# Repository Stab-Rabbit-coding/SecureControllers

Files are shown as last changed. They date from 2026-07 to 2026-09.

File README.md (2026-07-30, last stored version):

# SecureControllers
unmanned system controllers with security baked in. 

These started as the avionics suite for the Serenity UAV, but aren't limited to that.

1. EMI-Hardened Beagle Capes

    * PocketBeagle2-I Secure Flight Controller
    * PocketBeagle2-I Secure Communications
    * PocketBeagle2-I Sub-Gigahertz Trustworthy Transceiver

2. Trustworthy Sensor R-PI HATs

2. Trustworthy Gateway devices

    * Stackable CAN+RS-485 peripherals Gateway for GPIO/SPI/TTL/ADC/DAC/UART with a TPM.

3. Trustworthy Final Control Elements

    * 50A ESC
    * digital servo
    * Camera/Laser pod
    * Power Distribution Board

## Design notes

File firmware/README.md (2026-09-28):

# Serenity UAV — Firmware

**Author:** Steve Griffing, PE(CSE), CISSP-ISSEP, CPP
**License:** CC BY 4.0 — creativecommons.org/licenses/by/4.0
**Status:** Phase 6 — Minimum Viable Firmware for First Flight

---

## Overview

This directory contains the userspace firmware daemons that run on the eight
PocketBeagle 2 Industrial (AM6254) single-board computers in the Serenity UAV.

The AM6254 runs **BeagleBone Debian Trixie** from onboard 64 GB eMMC; these daemons
are standard Linux processes that use POSIX APIs, i2c-dev, libgpiod 2.x, and pthreads.

## Node Groups

| Group | Count | Cape | Responsibilities |
| --- | --- | --- | --- |
| FC nodes | 4 | Cape-A | Flight control, navigation, obstacle avoidance, ESC/actuator drive |
| CN nodes | 4 | Cape-B | Radio links, system logging, payload/cargo management |

## Cape Variant Placement

The eight nodes use a **v2 · v2 · v2 · v2** (nose → tail) cape variant layout — Rev R all-EMI-hardened:

| Bay | Room name | Pair | FC cape | CN cape | Rationale |
|-----|---|---|---|---|---|
| A (nose) | Shepherd's room | FC1 / CN1 | Wash | TACCO | Bus start termination; 5 kV isolated CAN FD / RS-485 / Ethernet at forward bus endpoint |
| B | Inara's shuttle | FC2 / CN2 | Wash | TACCO | Rev R: uniform EMI hardening across all bays |
| D | River's room | FC3 / CN3 | Wash | TACCO | Rev R: uniform EMI hardening across all bays |
| E (tail) | Simon's medbay | FC4 / CN4 | Wash | TACCO | Bus end termination; 5 kV isolation closest to nacelle motor wiring / rear EDF |

Rev R places 5 kV galvanic isolation at every node. Cape-A-1 / Cape-B-1 are archived (Rev Q, 2026-06-05).

## Directory Layout

```text

firmware/
├── common/
│   └── include/         # Shared headers used by both FC and CN daemons
│       ├── kiss_types.h # KISS protocol constants (RFC 1055 / Chepponis & Karn 1987)
│       └── ax25_types.h # AX.25 v2.2 frame type definitions
├── cn/                  # CN node daemon (runs on all 4 Cape-B / AM6254 nodes)
│   ├── CMakeLists.txt
│   └── src/
│       ├── main.c       # Daemon entry point, argument parsing, signal handling
│       ├── si5351.h     # Si5351A DDS I²C driver API
│       ├── si5351.c     # Si5351A frequency programming (49 MHz Part 15 §15.235 channels)
│       ├── xcvr_kiss.h  # XCVR-49MHZ-1 KISS/AX.25 driver API
│       └── xcvr_kiss.c  # KISS framing, PTT sequencing, UART I/O
├── fc/                  # FC node daemon (stub — Phase 7)
│   ├── CMakeLists.txt
│   └── src/
│       └── main.c       # FC node entry point stub
└── CMakeLists.txt       # Top-level build

```

## Build

### Target Platform

| Item | Value |
| --- | --- |
| Board | PocketBeagle 2 Industrial (DigiKey 2820-100003007-ND) |
| SoC | TI AM6254 (quad Cortex-A53 @ 1.4 GHz, dual PRU-ICSS) |
| OS | BeagleBone Debian Trixie (libgpiod 2.2.1, Linux ≥ 6.1) |
| Storage | 64 GB eMMC (no OS microSD) |

### Prerequisites (cross-compilation host, Ubuntu 24.04+)

```bash

# Cross-compiler and CMake

sudo apt install cmake gcc-aarch64-linux-gnu libc6-dev-arm64-cross

# libgpiod 2.x headers and static lib for aarch64

# Debian Trixie sysroot required — or use multiarch on a Trixie host:

#   sudo dpkg --add-architecture arm64

#   sudo apt install libgpiod-dev:arm64

```

> **NOTE:** Builds shall use **libgpiod 2.x** (Debian Trixie ships 2.2.1).
> The libgpiod 1.x API (Ubuntu 24.04) is **incompatible** with this code.
> Build directly on a PocketBeagle 2 or in a Trixie arm64 container if
> a full cross-compilation sysroot is not available.

### Build on the PocketBeagle 2 itself (simplest for Phase 6)

```bash

# On the PocketBeagle 2 running Debian Trixie:

sudo apt install cmake build-essential libgpiod-dev

git clone <repo> && cd Serenity-UAV/serenity/firmware
mkdir build && cd build
cmake ..
cmake --build .
sudo cmake --install .

```

### Cross-compile for AM6254 (aarch64) — advanced

```bash

mkdir build && cd build
cmake .. -DCMAKE_TOOLCHAIN_FILE=../cmake/aarch64-linux-gnu.cmake
cmake --build .

```

## Deployment

```bash

# Install via cmake on the target, or copy manually:

scp build/cn/serenity-cn debian@pocketbeagle2-cn1:/usr/local/bin/
scp build/fc/serenity-fc debian@pocketbeagle2-fc1:/usr/local/bin/

```

Systemd unit files are in `cn/serenity-cn.service` and `fc/serenity-fc.service` (Phase 7).

## Security

All inter-node messages are digitally signed using the node's TPM 2.0 (SLB9670).
The signing key is bound to the TPM's PCR state at boot (measured boot).
The AX.25 payload carries a SHA-256 HMAC before KISS framing; the CN node
verifies the HMAC on received frames before forwarding to the AX.25 stack.
Key management uses the Linux TPM2 PKCS#11 provider (`pkcs11-provider`).

## References

- AX.25 Link Access Protocol v2.2, ARRL, 1998
- KISS TNC Protocol: Chepponis & Karn, ARRL 6th Computer Networking Conference, 1987
- Si5351A/B/C-B Datasheet, Skyworks (formerly Silicon Labs), Rev 1.4
- 47 CFR Part 15 §15.235 — Operation within the band 49.82–49.90 MHz
- libgpiod API documentation — kernel.org
- Linux i2c-dev interface — kernel.org/doc/Documentation/i2c/dev-interface.rst

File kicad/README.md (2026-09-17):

# Serenity Avionics — KiCad Cape Status & Build Notes

This directory holds the KiCad projects for the four cape/board types:

| Project | Name | Role |
| --- | --- | --- |
| `Wash.kicad_*` | **Wash** | Flight-control & sensor cape (FC) |
| `TACCO.kicad_*` | **TACCO** | Comms / logging / payload cape (CN) |
| `FlightEngineer.kicad_*` | **FlightEngineer** | Power-distribution board (PDB) |
| `Emma.kicad_*` | **Emma** | 49 MHz (Part 15 §15.235) transceiver |
| `Observer.kicad_*` | **Observer** | Nose/Cargo vision, ToF, & laser board (standalone) |

Per-board net/pin documentation lives in the matching `*.md` files
(`Wash.md`, `TACCO.md`, `FlightEngineer.md`, `XCVR-49MHZ-2.md`). KiCad files keep
KiCad board coordinates (documented exception to the hull-frame standard,
see root `CLAUDE.md`).

---

## DRC / routing work — what was done and what was not (2026-06-12)

A pass was made to wire in a second Ethernet channel and to clear the
Design-Rule-Check (DRC) and ratsnest issues introduced by a manual
component rearrangement. This section records exactly what landed and
what is still open, so the thread can be picked up cleanly.

### ✅ Done

- **Second Ethernet (ETH2) wired on Wash.** The newly placed `ETH2`
  (JST-GH-4P), `ETH2-PHY` (ADIN1300BCPZ), and `T-ETH2` (749010012A
  magnetics) footprints were present but unconnected. Their nets now
  mirror the ETH1 topology exactly:

  ```text
  ETH2 ──ETH2_LINE_{TX,RX}{P,N}──► T-ETH2 ──ETH2_{TX,RX}{P,N}──► ETH2-PHY
  ```

  The host side reuses the nets already broken out on the **PB2-P2**
  header: the `RMII1_*` bus, shared `MDIO`/`MDC`, `PHY2_INTRN`/
  `PHY2_RSTN`, and the `VCC2_ETH` / `GND` / `GND2_ETH` power and
  isolation domains. 44 pads assigned (ETH2-PHY 32, T-ETH2 8, ETH2 4);
  diff-pair chains verified end-to-end. *(Delivered in PR #59.)*

- **Split the two Wash PHYs onto independent MDIO buses (2026-06-12).** Instead
  of an address strap on a shared bus, PHY1 now uses `MDIO0`/`MDC0` (the CPSW
  MDIO controller, PB2-P2 pins 17/18) and PHY2 uses `MDIO1`/`MDC1` (PB2-P2 pins
  1/2, the two spare servo channels SERVO6/7). Each PB2-I NIC manages its own
  PHY — no shared-address conflict. Both the PCB nets and the schematic global
  labels were updated. *Firmware note:* PHY2's bus is a second (bit-banged
  `mdio-gpio`) MDIO; confirm the two repurposed balls are GPIO-capable in the
  PB2-I pinmux.

- **Wired the floating field connectors to their signals (2026-06-12).** Every
  JST field connector was placed but had no nets. Using each footprint's
  Description pinout: SERVO-PWM pads 1–6 → `SERVO0–5` (servo PWM); ESC-TLM →
  `UART_ESC_TX`/`RX`; GPIO-A…F → `GND`/`+3V3` (+ labelled `GPIO_EXP_*` signal);
  CAN-FD → `CAN_H`/`CAN_L`; RS-485 → `RS485_A`/`B`; PWR-IN → `+5V`/`GND`. The
  new connector shorts that DRC now reports are all against `TMESH_*` (the
  pre-existing tamper-mesh overlap, resolved by the mesh rework below) — not the
  connector wiring itself.

- **Confirmed the design is PCB-driven.** Each cape's schematic
  (`*.kicad_sch`) defines only the PocketBeagle-2 header pin-mux (the
  PB2-P1/P2 connectors with the RMII0/RMII1/MDIO net labels); every other
  component lives as a PCB footprint with nets assigned directly on the
  board. "Update PCB from Schematic" therefore does **not** repopulate
  the component nets — net edits are made on the `.kicad_pcb`.

- **Verified the boards load** in `pcbnew` (Wash 43, TACCO 42, Emma 69,
  FlightEngineer 67 footprints) and characterised the violation landscape (below).

### ❌ Not done — open follow-up

1. **Tamper mesh (`TMESH_P`/`TMESH_N`).** Drawn today as a raw
   cross-hatch grid on F.Cu/B.Cu that **shorts across SMD pads and across
   the isolated `GND2_*` domains** — this is the single largest source of
   DRC errors (≈335 of Wash's 465; similar on TACCO). The agreed design is
   a **per-domain anti-tamper mesh**: a separate monitored mesh net per
   isolation region (secure/`GND` area plus one per `GND2_CAN` / `GND2_ETH`
   / `GND2_RS485` field side), with the 0.5 mm `ISOLATION` creepage moat
   kept clear between them. Wash and TACCO tie their mesh to the local TPM;
   **FlightEngineer and Emma have no local TPM**, so their tamper signal must be
   carried over the inter-board link (Emma → TACCO, FlightEngineer → Wash).

2. **Routing / ratsnest.** The manual rearrangement left signal nets
   unrouted (~60 multi-pin signal nets per cape; the 7 power/ground nets
   are intended as planes). This was **not** completed — see the toolchain
   findings below for why headless autorouting did not produce a
   trustworthy result. The impedance-controlled Ethernet pairs should be
   routed interactively (length-matched / controlled-impedance) regardless.

3. **Remaining DRC.** After the mesh and routing are fixed, the residual
   cosmetic/footprint items still need clearing (counts measured
   2026-06-12, error+warning):

   | Board | violations | unconnected | dominant types |
   | --- | --- | --- | --- |
   | Wash | 465 | 121 | mesh shorts, solder-mask bridges, clearance |
   | TACCO | 554 | 146 | mesh shorts, solder-mask bridges, clearance |
   | Emma | 421 | 160 | silk-over-copper, text-height, mask bridges |
   | FlightEngineer | 221 | 181 | courtyard overlap, lib-footprint mismatch, silk |

4. **MDIO addressing.** Both Wash PHYs (ETH1-PHY, ETH2-PHY) share the
   `MDIO`/`MDC` management bus but there are **no address-strap resistors
   on the board**, so both default to the same MDIO address. A strap
   (or a decision to manage each PHY only over its own RMII channel) is
   required before the second PHY is manageable. Not invented here because
   no strap-resistor footprints are placed.

---

## Toolchain findings (headless KiCad 9 + freerouting)

These are recorded so the next person does not re-derive them:

- **KiCad 9.0.2 `pcbnew.ExportSpecctraDSN()` is non-functional in
  standalone Python** — it returns `False` with no GUI/kiway context
  (`pcbnew.GetBoard()` is `None`). Loading a project, building
  connectivity, initialising a `wx.App`, and running under Xvfb all make
  no difference; it is a binding limitation, not a display issue.

- A custom headless **Specctra DSN exporter + SES importer** (driven
  entirely through the working board API) was written to bridge this. The
  round-trip is mechanically correct (valid DSN out, freerouting routes
  it, SES tracks/vias re-imported at the right coordinates).

- **freerouting 2.1.0 headless is unreliable for a complete route on this
  toolchain**: it must be run **without** a display (with Xvfb it opens
  the GUI and hangs); it never self-exits (must be killed after the SES is
  written); its multi-threaded optimiser is broken (use `-mt 1`); and the
  SES it emits captured only a handful of nets rather than the full
  ~60-net set. It was therefore **not** used to route the boards.

- **Recommended workflow:** finish routing in the **KiCad GUI** (where
  Specctra DSN export and the interactive/auto routers are reliable), with
  the Ethernet pairs routed by hand. The deterministic, non-routing work
  (per-domain tamper-mesh zones, cosmetic/footprint DRC, the Emma/FlightEngineer
  link tamper signalling) can still be scripted headless via the board API.

---

*Author: Steve Griffing, PE(CSE), CISSP-ISSEP, CPP · License: CC BY 4.0*

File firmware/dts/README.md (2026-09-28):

# Serenity UAV — Device Tree Overlays

**Author:** Steve Griffing, PE(CSE), CISSP-ISSEP, CPP
**License:** CC BY 4.0 — creativecommons.org/licenses/by/4.0
**Status:** Phase 6 — Minimum Viable Firmware for First Flight

---

## Overview

This directory contains the AM62X device tree overlays that configure the
PocketBeagle 2 Industrial (AM6254) peripherals for the Serenity UAV Cape-A
and Cape-B expansion boards.

| Overlay | Cape | Node | Peripherals |
| --- | --- | --- | --- |
| `cape-a/k3-am6254-pocketbeagle2-serenity-cape-a.dtbo` | Cape-A | FC nodes (4×) | IMU, barometer, TPM, ToF, GNSS, RS-485, CAN FD, Ethernet, EHRPWM, MIL-STD-1553 |
| `cape-b/k3-am6254-pocketbeagle2-serenity-cape-b.dtbo` | Cape-B | CN nodes (4×) | TPM, LoRa, NOR flash, logging SD, SiK radio, RS-485, 49 MHz (Part 15 §15.235), CAN FD, Ethernet, WiFi, cargo servo, MIL-STD-1553 |

## Prerequisites

```bash

# On the PocketBeagle 2 (Debian Trixie) or cross-compilation host:

sudo apt install device-tree-compiler    # provides dtc 1.7.x

```

`dtc` version 1.7 or later shall be used, for the `-@` flag (generates
`__symbols__` section enabling runtime overlay application).

## Build

```bash

cd serenity/firmware/dts
make

```

This produces `cape-a/*.dtbo` and `cape-b/*.dtbo`.

## Install

```bash

# Copy compiled overlays to the PocketBeagle 2 boot partition.

# Must be run as root on the target board.

sudo make install

```

Then edit `/boot/firmware/extlinux/extlinux.conf` and add the appropriate
`fdtoverlays` line under your `LABEL` stanza:

```text

# FC nodes (Cape-A):

fdtoverlays /overlays/k3-am6254-pocketbeagle2-serenity-cape-a.dtbo

# CN nodes (Cape-B):

fdtoverlays /overlays/k3-am6254-pocketbeagle2-serenity-cape-b.dtbo

```

Each node loads only one overlay (the one matching its installed cape).

## Pad Offset Verification

All `AM62X_IOPAD` offsets tagged `[ESTIMATE]` in the DTS source files
**shall be verified** before production use by cross-referencing:

1. **TI AM6254 TRM, SPRUJ40**, Table 7-1 "MAIN Domain Pad Control Registers"

- Step 2: **PocketBeagle 2 Industrial schematic** (BeagleBoard.org hardware repo),

   which maps AM6254 ball numbers to P1/P2 expansion header pins.

Offsets tagged `[CONFIRMED]` are sourced from `k3-am625-sk.dtsi` in the
Linux 6.x kernel tree and have been validated against production hardware.

GPIO line numbers are logical (relative to `main_gpio0`) and shall also
be verified against the PocketBeagle 2 expansion header pin map.

## Cape-A Peripheral Details

| Peripheral | Interface | Linux Driver | Notes |
| --- | --- | --- | --- |
| ICM-42688-P IMU | SPI0 CS0 | `invensense,icm42688p` | SPI mode 3, 24 MHz |
| BMP388 barometer | SPI0 CS1 | `bosch,bmp388` | SPI mode 0, 10 MHz |
| SLB9670 TPM 2.0 | SPI0 CS2 | `infineon,slb9670` | 33 MHz, IRQ + RST GPIO |
| TCA9548A I²C mux | I2C2 0x70 | `nxp,pca9548` | 8-ch, 400 kHz |
| VL53L5CX ToF ×2 | I2C2 mux ch0/1 | `st,vl53l5cx` | 0x29, share addr |
| MS4525DO airspeed | I2C2 mux ch2 | `ms4525do` | FC1 only |
| Debug console | UART0 | n/a | 115200 8N1 |
| ESC telemetry | UART1 | n/a | BLHeli32 / Hobbywing |
| u-blox M10Q GNSS | UART3 | gpsd | 38400 baud default |
| RS-485 MAX3485E | UART4 | n/a | DE/RE# GPIO direction |
| CAN FD ATA6561 | MCAN0 | `m_can` | 1/8 Mbps |
| Ethernet DP83825I ×2 | CPSW3G | `dp83825i` | 100BASE-TX RSTP ring |
| EHRPWM 0-2 | — | `pwm` | 6ch servo/ESC PWM |
| MIL-STD-1553B | PRU-ICSS0 PRU0 | n/a | Manchester II 1 Mbps |
| Extra PWM ch 6-7 | PRU-ICSS0 PRU1 | n/a | 1 µs resolution |

## Cape-B Peripheral Details

| Peripheral | Interface | Linux Driver | Notes |
| --- | --- | --- | --- |
| SLB9670 TPM 2.0 | SPI1 CS0 | `infineon,slb9670` | HMAC keys for radio frames |
| RFM95W LoRa 915 | SPI1 CS1 | `semtech,sx1276` | 47 CFR Part 15 Subpart C |
| W25Q128JV NOR flash | SPI1 CS2 | `jedec,spi-nor` | 16 MiB, 3 partitions |
| Logging microSD | SPI1 CS3 | `mmc-spi-slot` | ext4, noexec, CPLD WP |
| RFD900x SiK 915 MHz | UART2 | n/a | MAVLink, HW CTS/RTS |
| RS-485 MAX3485E | UART4 | n/a | DE/RE# GPIO direction |
| XCVR-49MHZ-1 (49 MHz Part 15) | UART5 | n/a | AX.25, 57600 8N1, PTT_N GPIO |
| CAN FD ATA6561 | MCAN0 | `m_can` | 1/8 Mbps |
| Ethernet DP83825I ×2 | CPSW3G | `dp83825i` | 100BASE-TX RSTP ring |
| WL1837MOD WiFi | MMC1 / SDIO | `ti,wl1837` | 5 GHz 802.11ac, 4-bit |
| EHRPWM0 | — | `pwm` | 2ch cargo servo/gimbal |
| MIL-STD-1553B | PRU-ICSS0 PRU0 | n/a | RT mode only on CN nodes |
| Cargo PWM + TDDS | PRU-ICSS0 PRU1 | n/a | 2ch servo + Si5351 sync |

## PRU Firmware

PRU firmware binaries shall be installed to `/lib/firmware/serenity/` on
the target before loading the overlays:

```bash

sudo mkdir -p /lib/firmware/serenity/
sudo cp pru0-mil1553.out   /lib/firmware/serenity/
sudo cp pru1-servo-pwm.out /lib/firmware/serenity/    # Cape-A PRU1
sudo cp pru1-cargo-servo.out /lib/firmware/serenity/  # Cape-B PRU1

```

PRU firmware source is in `serenity/firmware/pru/` (Phase 7).

## References

- TI AM6254 Technical Reference Manual, SPRUJ40
- TI AM62x SK EVM device tree, `k3-am625-sk.dtsi`, Linux 6.x kernel
- PocketBeagle 2 Industrial schematic — BeagleBoard.org hardware repository
- BeagleBone Debian Trixie `extlinux.conf` overlay documentation
- MIL-STD-1553B, DoD Interface Standard, 21 Sep 1978
- 47 CFR Part 15 §15.235 (49 MHz channel plan; not Part 95 RCRS, which does not cover this band)
- 47 CFR Part 15 Subpart C (unlicensed 915 MHz LoRa)

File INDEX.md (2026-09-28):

# Workspace Resource Index

`SecureControllers` is the canonical library for reusable hardware design
assets across the Browncoats workspace (`designs/`) — **copy-with-index**,
not a git submodule or symlink. Canonical, verified copies of shared
datasheets, KiCad symbols/footprints, and mechanical shapes live in this
repo's `datasheets/`, `kicad/`, and `shared.3dshapes/` directories, each with
a recorded SHA-256 hash. Consuming repos keep their own local copies; this
index is how you check whether yours matches the canonical one, and where to
find a verified asset before adding a new copy.

This repo also carries a full local library of **agent skills** (128, under
`.claude/skills/`) usable by any Claude Code session — local or cloud/web —
running against this repo or branch. That library has its own token-optimized
index: [`.claude/skills/INDEX.md`](.claude/skills/INDEX.md). Same lookup
pattern as this file, different asset type — use that one for "which skill do
I invoke for this task," use this one for "which datasheet/symbol/footprint/
shape/script already exists."

Full plan and rationale:
[`docs/plans/2026-09-08-001-feat-workspace-resource-library-plan.md`](docs/plans/2026-09-08-001-feat-workspace-resource-library-plan.md).
GitHub issue tracking all four phases:
[`SecureControllers#1`](https://github.com/Stab-Rabbit-coding/SecureControllers/issues/1).

## How to look something up (minimum token cost)

Read **one** manifest file below for your asset type — never grep the PDFs,
`.kicad_sym`/`.kicad_mod` files, or shape files themselves, and never load
more than one manifest for a single lookup.

| Looking for... | Read this file | Key field to match on |
| --- | --- | --- |
| A datasheet by part number | `index/datasheets.json` | `mpn_guess` (Tier B-confirmed once `verified: true`) |
| A KiCad symbol | `index/kicad-symbols.json` | `symbol_or_footprint_name` |
| A KiCad footprint | `index/kicad-footprints.json` | `symbol_or_footprint_name` |
| A mechanical shape (STEP/WRL/STL) | `index/shapes.json` | `basename` |
| A shared script/tool | `index/scripts.json` | `path` |
| A workspace-wide knowledge resource (e.g. `engineering-pe-skills`) | `index/knowledge.json` | `path`, `description` |
| An agent skill available in *this* repo | `.claude/skills/INDEX.md` (or `index/skills.json`) | skill directory name, `description` |
| Whether a repo has assets yet | `index/placeholders.json` | `repo` |

There is currently no single-file "everything from repo X" lookup — that
would require reading each type manifest and filtering by `repo`. See the
Open Questions in the plan (per-repo lookup surface) before relying on one;
none exists yet.

Every entry carries `verification_tier` (`unverified` until Phase 2 runs,
then `"A"` = full pin/pad-verified, `"B"` = provenance/hash-verified, `"C"` =
placeholder-only) and `verified: true/false`. An entry with
`possible_duplicate: true` or `renamed_duplicate: true` has a same- or
differently-named twin in another repo — check `canonical_path` (once Phase 3
runs) for which copy is authoritative.

## Current scope (as of the last scan)

| Repo | Datasheets | KiCad symbols | KiCad footprints | Shapes | Scripts |
| --- | ---: | ---: | ---: | -----: | ---: |
| Serenity-UAV | 50 | 9 | 17 | 367 | 46 |
| SecureControllers | 48 | 8 | 15 | 37 | 3 |
| Open-Secure-ESC | 58 | 20 | 9 | 1 | 0 |
| open-servo-core-secure | 11 | 1 | 40 | 37 | 0 |
| LibreServo_v4 | 26 | 2 | 22 | 3 | 0 |
| Tactical-WX-RX | 3 | 0 | 0 | 0 | 0 |

"Scripts" counts only top-level `tools/` directories (per the provisional
classification rule below) — nested per-board generator/fixup scripts (e.g.
`Open-Secure-ESC`'s many `kicad/<board>/tools/*.py` one-offs) are
intentionally excluded, not missed.

`engineering-pe-skills` is indexed separately as a **knowledge asset** (4
skill entries in `index/knowledge.json`) — it has no MPN/hash-drift concerns
in the hardware sense, but is still a citable reusable resource.

**Placeholder-hook repos** (no hardware assets yet — `index/placeholders.json`):
Bento-boat, TidySweep, obd2-recorder, dasGoat-USV. Consult this index when
starting hardware work in any of them.

**Confirmed cross-repo duplication:** 87 of 175 cataloged datasheets and 74 of
445 shape entries (`possible_duplicate: true` in `index/datasheets.json` /
`index/shapes.json`) already have a same-named copy in another repo — this is
exactly the drift risk this index exists to catch. 4 renamed-but-content-
identical datasheet duplicates were also found (`renamed_duplicate: true`).

## Verification tiers (Phase 2 / U4, not yet run)

- **Tier A** — full pin/pad-level check against the source datasheet. Applied
  to flight-critical parts and anything already flagged as suspect (e.g. the
  7 known-bad Wash footprints tracked in `TODO.md`).
- **Tier B** — provenance + cross-repo hash-consistency check. Everything
  else.
- **Tier C** — placeholder only, no file to verify (the four empty repos).

See the plan's Open Questions for two items that block a clean Tier-A pass:
worklist completeness for un-audited flight-critical parts, and the
provisional "scripts live under `tools/`" classification rule used by
`tools/inventory_scan.py`.

## Regenerating the index

```bash
/usr/bin/python3 tools/inventory_scan.py    # rescan all repos -> index/_raw/*.json
/usr/bin/python3 tools/build_manifests.py   # rebuild index/*.json from the raw scan
```

Both scripts are stdlib-only (no `kiutils`/`manifold3d` dependency) and shall
be run with `/usr/bin/python3`, not a repo's local `.venv`, which shadows
system packages without providing everything the workspace tooling needs.

## Cross-links from consuming repos

Each consuming repo's own `AGENTS.md`/`CLAUDE.md` carries a one-line pointer
back to this file (Phase 4 / U6) — check there first if you arrived at a
board's design docs and are wondering whether an asset already exists
elsewhere in the workspace.

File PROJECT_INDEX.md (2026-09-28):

# Project Index — SecureControllers

Directory structure and active files, per the repository-root governance
convention in the user's global `CLAUDE.md`. For high-volume, single-format
directories (datasheets, KiCad symbols/footprints, shared 3D shapes), this
file gives the directory-level shape; the authoritative per-file listing
(with hash, MPN guess, verification tier, and cross-repo duplicate flags) is
[`INDEX.md`](INDEX.md) and the machine-readable manifests under `index/`.
Duplicating hundreds of filenames here as well would drift out of sync with
the generated manifests on every rescan — regenerate `index/*.json` via
`tools/inventory_scan.py` / `tools/build_manifests.py`, not this file, and
treat those as the source of truth for asset inventories.

## Root

| Path | Purpose |
| --- | --- |
| `.claude/` | Claude Code project config; `.claude/skills/` is the local agent-skills library (128 skills) — see below |
| `CLAUDE.md` | Avionics design project instructions (Serenity-UAV subsystem scope; this repo also serves as the workspace library — see Open Questions in the plan below) |
| `.gitignore` | Excludes `__pycache__/`, `*.pyc` |
| `INDEX.md` | Workspace resource library entry point — read this first for asset lookups |
| `LICENSE.md` | Repository license |
| `not-a-real-datasheet.txt` | Test fixture (deliberately not a real datasheet; excluded from the scanner's matched extensions) |
| `PROJECT_INDEX.md` | This file |
| `SecureControllers.code-workspace` | VS Code workspace file |
| `TODO.md` | Work Breakdown Structure. Currently scoped as "Serenity UAV — Avionics WBS"; identity vs. this repo's new workspace-library role is an open question in the plan (see `docs/plans/`) |

## `.claude/skills/`

128 agent skills (security/SOC, GRC compliance, PE-aligned engineering,
PCB/KiCad, compound-engineering, dev-workflow) mirrored into this repo from
the user's `~/.claude/skills/` and plugin installs, so they're available to
any Claude Code session — local or cloud/web — running against this repo or
branch, not just this machine. Human/agent-searchable index, grouped by
category, one-line description per skill:
[`.claude/skills/INDEX.md`](.claude/skills/INDEX.md). Machine-readable form:
`index/skills.json`. Regenerate after adding/removing/editing a skill:
`python3 tools/build_skills_index.py`.

Excluded from this mirror: `pr-review-toolkit`, `security-guidance`, and
`github` plugins — they ship as agents/hooks/commands, not `SKILL.md`
folders, so there was nothing skill-shaped to copy.

## `datasheets/`

48 manufacturer/standards PDFs (ISOW1044, SLB9670, ADIN1300, ADM2795E,
BMP388, SAM-M10Q, NIST SP 800-series, etc.). Full per-file listing with
MPN guesses: `index/datasheets.json`.

## `docs/`

| Path | Purpose |
| --- | --- |
| `docs/plans/` | Compound-engineering plan documents (`ce-plan` output). Currently: `2026-09-08-001-feat-workspace-resource-library-plan.md` |

## `firmware/`

Zephyr-based firmware tree, shared across the CN (comms node) and FC
(flight-control node) capes.

| Path | Purpose |
| --- | --- |
| `firmware/CMakeLists.txt` | Top-level build |
| `firmware/README.md` | Firmware build/flash instructions |
| `firmware/common/` | Shared code between CN and FC (`include/`, `src/`) |
| `firmware/cn/` | Comms-node-specific firmware (`src/`) |
| `firmware/fc/` | Flight-control-node-specific firmware (`src/`, `tools/`) |
| `firmware/dts/` | Devicetree overlays for `cape-a`/`cape-b`, `Makefile`, `README.md` |

## `index/` (generated — do not hand-edit)

| Path | Purpose |
| --- | --- |
| `index/_raw/<repo>.json` | Raw per-repo scan output from `tools/inventory_scan.py` |
| `index/datasheets.json` | Type-sharded datasheet manifest (196 entries workspace-wide) |
| `index/kicad-symbols.json` | KiCad symbol manifest (40 entries) |
| `index/kicad-footprints.json` | KiCad footprint manifest (103 entries) |
| `index/shapes.json` | Mechanical shape manifest, STEP/WRL pairs collapsed (445 entries) |
| `index/scripts.json` | Reusable top-level `tools/` script manifest (49 entries) |
| `index/knowledge.json` | `engineering-pe-skills` knowledge-asset manifest (4 entries) — workspace-wide, cross-repo; distinct from this repo's own `index/skills.json` |
| `index/skills.json` | This repo's local `.claude/skills/` agent-skills manifest (128 entries). See `.claude/skills/INDEX.md` for the human-readable form |
| `index/placeholders.json` | Empty-repo hooks (4 entries: Bento-boat, TidySweep, obd2-recorder, dasGoat-USV) |

## `kicad/`

| Path | Purpose |
| --- | --- |
| `kicad/symbols/` | Shared KiCad symbols + pinmap CSVs (ISOW1044BDFMR, KSZ9477, MSPM0G3507, SLB9670 TPM, SoM symbols) |
| `kicad/Serenity-Custom.pretty/` | Shared custom footprint library |
| `kicad/Vera.pretty/` | Vera-board-specific footprint library |
| `kicad/Emma/`, `kicad/Jayne/`, `kicad/Kaylee/`, `kicad/Wash/`, `kicad/Zoë/` | Per-board `kicads/`, `gerbers/`, `scripts/`, and board `.md` docs |
| `kicad/ENC-NACELLE-1.kicad_sch`, `.md` | Nacelle tilt-encoder schematic + notes |
| `kicad/*.py` | Per-board generator/fixup scripts (not indexed as reusable — see `INDEX.md`'s script-classification note) |
| `kicad/fp-lib-table`, `kicad/drc_report.txt`, `kicad/xcrv-DRC.rpt` | KiCad project config and DRC output |

## `shared.3dshapes/`

37 STEP/WRL/STL mechanical shape files for shared connectors, passives, and
packages (CONN-SMD/TH series, DFN/SON/SOT/QFN/UQFN/WSON/XSON packages,
USB-C, switches, LED). Full per-file listing: `index/shapes.json`.

## `tools/`

| Path | Purpose |
| --- | --- |
| `tools/inventory_scan.py` | Workspace-wide asset scanner (U1) — writes `index/_raw/*.json` and `index/placeholders.json` |
| `tools/build_manifests.py` | Builds the type-sharded `index/*.json` manifests from the raw scan (U2) |
| `tools/build_skills_index.py` | Builds `index/skills.json` + `.claude/skills/INDEX.md` from this repo's local `.claude/skills/` — separate from the workspace-wide scan/manifest pair above |

Regenerate both after any workspace repo's assets change:
`/usr/bin/python3 tools/inventory_scan.py && /usr/bin/python3 tools/build_manifests.py`
(shall use `/usr/bin/python3`, not a repo-local `.venv`).

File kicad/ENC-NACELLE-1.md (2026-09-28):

# ENC-NACELLE-1 — Nacelle Tilt Angle Encoder Board

**Author:** Steve Griffing, PE(CSE), CISSP-ISSEP, CPP
**License:** CC BY 4.0 — creativecommons.org/licenses/by/4.0
**Revision:** R (Rev R baseline — initial design carried forward; no schematic changes)
**Status:** Schematic complete — PCB layout pending

---

## Purpose

ENC-NACELLE-1 is a miniature magnetic rotary encoder board that measures the tilt
angle of each nacelle in the Serenity UAV.  One board is installed per nacelle
(port and starboard) at the outboard end of the wing spar where the nacelle pivot
bearing is located.

The board reports 12-bit absolute angle data to the flight control Wash node
via a shielded I²C cable (ENC_SDA / ENC_SCL), allowing the PID controller to close
the tilt servo loop with continuous angle feedback.

---

## Design Rationale

### Sensor Technology Selection

Optical encoders were considered and rejected because the nacelle pivot is located in
the EDF exhaust stream where carbon fibre dust, moisture, and potential debris
contamination make optical sensing unreliable.

The AMS AS5600 12-bit magnetic rotary position sensor was selected:

- **No contact, no contamination path** — reads a diametrically magnetised diametric
  magnet through a gap of 0.5 – 3 mm; sealed from the environment.
- **Adequate resolution** — 12-bit = 4096 counts/revolution, 0.088°/LSB; the nacelle
  tilt servo requires ≤ 0.1° angular resolution for stable PID hover.
- **Sufficient RF immunity** — at 500 W/m² (E = 434 V/m), the associated magnetic
  field H = 1.15 A/m ≈ 1.45 µT.  The encoder reads a 50–100 mT permanent magnet;
  the external threat field is < 0.003 % of the sensor signal — completely negligible.
- **Simple I²C interface** — single fixed address (0x36), standard mode 100 kHz,
  compatible with PocketBeagle 2 I2C3 peripheral.
- **Small size** — SOIC-8 package, fits a 15 × 15 mm PCB.

---

## Bill of Materials

| Ref  | Value / MPN | Description | Package |
|---|---|---|---|
| U1 | AMS AS5600 | 12-bit magnetic rotary position sensor | SOIC-8 |
| D1 | Nexperia PRTR5V0U2X | Dual-channel ESD protection, 5 V clamp | SOT-363 |
| C1 | 100 nF X5R ≥ 6.3 V | VDD bypass decoupling | 0402 |
| R_DIR| 10 kΩ 1 % 0402 | DIR pull-down to GND (CCW direction) | 0402 |
| R_PGO| 10 kΩ 1 % 0402 | PGO pull-up to +3V3 (output disabled) | 0402 |
| J1 | JST SM04B-GHS-TB (shielded body)  | 4-pin GH cable connector to Wash | TH right-angle|
| — | Diametrically magnetised magnet | 6 mm diam × 2.5 mm axial, N42 grade | Press-fit |

### Magnet Specification

- **Type:** Diametrically magnetised cylindrical (axial field).
- **Dimensions:** 6 mm diameter × 2.5 mm height.
- **Material:** NdFeB N42 (B_r ≈ 1.32 T).
- **Air gap to IC:** 0.5 – 1.5 mm target; AS5600 AGCM AGC output used to verify gap.
- **Mounting:** Press-fit into a recess in the nacelle pivot shaft end cap;
  shaft made of non-magnetic aluminium or PETG.

---

## Schematic Description

### J1 — Cable Connector

JST SM04B-GHS-TB (shielded body), right-angle, mates with JST GHHR-04V-S on the
STP cable from Wash J_ENC.

| Pin | Signal | Description |
|-----|---|---|
| 1 | GND | Power and signal return |
| 2 | +3V3 | 3.3 V power from Wash |
| 3 | ENC_SDA  | I²C SDA (to/from Wash) |
| 4 | ENC_SCL  | I²C SCL (from Wash) |
| MP  | SHIELD | Cable shield; floating at this board end  |

**Shield note:** The cable drain wire connects to PGND at the Wash J_ENC MP pin
only.  The shield is left floating (not connected) at J1 MP on this board to prevent
ground loops.  The board GND is a clean signal ground, not chassis PGND.

### D1 — ESD / EMI Protection (PRTR5V0U2X)

The Nexperia PRTR5V0U2X dual-channel ESD / EMI protection device is inserted in
series on both SDA and SCL lines between J1 and U1.  Features:

- Bidirectional ESD protection per IEC 61000-4-2 Level 4 (±8 kV contact).
- Internal low-pass EMI filter (R = 10 Ω typ, C = 0.7 pF typ per channel).
- V_clamp = 5 V; compatible with 3.3 V I²C logic.
- V_cc pin tied to +3V3; GND pin tied to GND.

### U1 — AS5600 Magnetic Encoder

Connected to ENC_SDA / ENC_SCL directly from D1 outputs.

| Pin | Net | Configuration |
|-----|---|---|
| 1 | VDD | +3V3; 100 nF C1 within 2 mm |
| 2 | GND | Signal ground |
| 3 | DIR | Pulled to GND via R_DIR 10 kΩ (CCW) |
| 4 | OUT | Analog / PWM output — no connect (NC) |
| 5 | GND2 | Signal ground (tied to pin 2) |
| 6 | SDA | I²C SDA via D1 |
| 7 | SCL | I²C SCL via D1 |
| 8 | PGO | Pulled to +3V3 via R_PGO 10 kΩ (output disable) |

**DIR = GND:** Defines angle counting direction as counter-clockwise when viewed from
the magnet face.  Direction is fixed at board level; software may negate if needed.

**PGO = +3V3:** Disables the OUT pin (pin 4) analogue/PWM output.  This pin is
high-impedance when PGO is high, reducing power and noise.

**I²C address:** Fixed at 0x36 (not configurable).

### R_DIR — Direction Pull-down

10 kΩ 0402, DIR (pin 3) to GND.  Sets CCW counting direction.

### R_PGO — Power / Output Mode

10 kΩ 0402, PGO (pin 8) to +3V3.  Disables OUT (pin 4) analogue output.

### C1 — VDD Bypass

100 nF 0402 X5R, +3V3 to GND, placed within 2 mm of U1 pin 1.

---

## PCB Physical Specification

| Parameter | Value |
|---|---|
| Board dimensions | 15 mm × 15 mm |
| Layer count | 2-layer (top + bottom) |
| PCB material | FR4 TG130 |
| Copper weight | 1 oz (35 µm) both layers |
| Surface finish | HASL lead-free or ENIG |
| Solder mask | Green, both sides |
| Silkscreen | White, top only |
| Connector location | J1 on board edge for right-angle cable exit |
| Magnet clearance | Centre of board over U1; 15 mm × 15 mm keeps |
| | the magnet centred over the pivot axis |

### Mounting

- Four M2 standoff holes at corners (2.5 mm from each edge).
- Standoffs: 5 mm length aluminium M2 (non-magnetic), M2 nylon screws.
- The board mounts on the wing spar end cap with U1 facing the nacelle pivot shaft.
- The diametrically magnetised magnet is press-fit into the pivot shaft end cap
  directly above U1 at the correct air gap (0.5 – 1.5 mm).

---

## Cable Assembly

| Parameter | Specification |
|---|---|
| Cable type | Belden 9367 STP, 2 × 28 AWG twisted pairs, PVC jacket|
| Pairs | Pair 1: ENC_SDA + GND; Pair 2: ENC_SCL + +3V3 |
| Length | 600 mm (nominal; measure per nacelle) |
| Wash end | JST GHR-04V-S, drain wire crimped to MP contact |
| ENC-NACELLE-1 end | JST GHR-04V-S, drain wire cut back and not connected  |
| Ferrite chokes | Würth 74271222 snap-on at both ends, over full bundle |
| Jacket colour | Grey or natural (to distinguish from power cables) |

---

## Installation Notes

1. **Pivot shaft material** shall be non-magnetic (aluminium 6061, PETG, or fibreglass).
   A steel or ferrite shaft will distort the field and invalidate angle readings.
2. **Magnet alignment:** Orient the magnet so the diametric axis is perpendicular to
   the pivot rotation axis.  The AS5600 detects the in-plane field component.
3. **Air gap verification:** After assembly, read the AS5600 AGC register (0x1A).
   AGC = 0 (minimum gain) → magnet too close; AGC = 255 → too far away.
   Target AGC = 50 – 200 for best linearity.
4. **Zero angle calibration:** Use the AS5600 ZPOS / MPOS registers or the software
   calibration offset to zero the angle at the hover (0°) nacelle position.
5. **Direction verification:** In hover, commanding nose-up nacelle tilt should
   produce increasing angle count.  If not, set the firmware direction flag.

---

## EMI Hardening

This board operates in the EDF nacelle at up to 500 W/m² (E = 434 V/m) field
strength from external RF sources.

| Measure | Implementation |
|---|---|
| ESD/EMI protection | PRTR5V0U2X on SDA and SCL lines |
| VDD bypass | 100 nF X5R within 2 mm of U1 |
| Cable shielding | Belden 9367 STP; single-point drain at Wash  |
| Ferrite chokes | Würth 74271222 at both cable ends |
| Magnet field vs. threat | 50–100 mT magnet vs. 1.45 µT external H-field; |
| | 34 000 : 1 signal-to-threat ratio |
| Physical enclosure | Nacelle EDF housing provides partial metal screen |

---

## Related Files

- `Wash.kicad_sch` — host flight control cape; provides J_ENC connector
- `Wash.md` — §13 documents the encoder interface, pull-ups, and GPIO assignment
- `XCVR-49MHZ-2.md` — companion 49 MHz transceiver board
- `TACCO.md` — companion comms/logging cape

---

## References

1. AMS AS5600 Datasheet v1-09 — ams-osram.com
2. Nexperia PRTR5V0U2X Datasheet — PRTR5V0U2X.pdf
3. Belden 9367 Cable Datasheet — belden.com
4. Würth 74271222 Ferrite Clamp Datasheet — we-online.com
5. IEC 61000-4-2:2008 — ESD immunity requirements
6. MIL-STD-461G:2015 — EM emissions and susceptibility requirements

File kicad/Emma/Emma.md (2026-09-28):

# Emma — EMI-Hardened 49 MHz AX.25 Transceiver

**Author:** Steve Griffing, PE(CSE), CISSP-ISSEP, CPP
**License:** CC BY 4.0 — creativecommons.org/licenses/by/4.0
**Revision:** S1 (Rev S baseline + schematic-first reconciliation 2026-07-04)
**Date:** 2026-07-04
**Status:** Schematic-first reconciliation COMPLETE — `Emma.kicad_sch` authored from the
as-placed PCB (`gen_emma_sch.py`), PCB transformed to match (`mod_emma_pcb.py`); sch↔pcb
parity exact (74 refs / 104 nets / 0 pin-count mismatches), ERC 0 errors. J1 (JST-GH-6P)
DROPPED — modem UART now rides the PB2-P1 rails (`UART_RCRS_RX`/`_TX`); PTT_N and a new
on-board `RSSI_DCD` carrier-detect ride presence-gated PB2-P2 payload GPIOs. Open (TODO.md
§1.2b): manual placement/routing of the 4 new RSSI parts (parked off-board), `RSSI_CMP`
part/pinout datasheet vetting, PTT/RSSI pinmux firmware sign-off, and 3 pre-existing
in-circuit stubs the schematic surfaced (`RF_ANT_SW`, `PA_EMIT`, `DDS_FSYNC`).

> **Note:** the "As-Built" tables below predate the 2026-07-04 reconciliation and still
> list J1 "CAPE-B IF" as present; J1 has since been removed and the modem UART moved to the
> PB2 rails. `Emma.kicad_sch` (not these tables) is now the source of truth.

---

## Purpose

Emma is an electromagnetic-environment-hardened variant of XCVR-49MHZ-1. The
board is a 49 MHz AX.25 KISS modem operating under 47 CFR Part 15 §15.235 (an unlicensed
intentional-radiator rule, not Part 95 RCRS — see REFERENCES.md REF-FCC-003); the -2 variant
adds conducted and radiated immunity measures to handle the EDF motor and ESC switching
environment inside the Serenity UAV nacelles.

All Phase 1 IC selections (Si5351A-B-GT DDS, MMBT2222A + 2N3866 PA, MCP4921 DAC,
LM393 comparator, MGA-82563 LNA, PE4259-63 T/R switch) are unchanged. The regulatory
constraints from XCVR-49MHZ-1 apply unchanged.

---

## Changes from XCVR-49MHZ-1

### 1. J1 host interface — EMI filter and protection

The 6-pin 2.54 mm pitch header J1 that connects to TACCO's RCRS-49 port is the
primary EMI ingress path. Any high-frequency conducted noise arriving on the UART and
PTT lines from the CAPE-B harness routes directly to the Si5351A logic interface
and MCP4921 SPI port. Emma adds a three-tier protection network:

## Tier 1 — Common-mode choke (CM5)

- Bourns SRF2012-100Y on the UART_TX/UART_RX pair (CM5)
- Placed between J1 and the Si5351A / MCU I²C interface
- Attenuates CM RF currents at the 49 MHz band and EDF switching harmonics (20–100 kHz)

## Tier 2 — Series ferrite beads

- Würth 742792510 (600 Ω @ 100 MHz, 100 mA, 0402) on UART_TX, UART_RX, and PTT_N,

  placed after CM5 toward the on-board circuitry

- Suppresses conducted EMI above 50 MHz that passes through the CMC

## Tier 3 — TVS protection array (TVS6)

- PRTR5V0U2X (NXP, dual-channel, 5.5 V clamp, SOT-363) on UART_TX and UART_RX
- Placed before CM5, immediately at J1 pin 3 and pin 4
- Clamps ESD / cable-injected transients to 5.5 V before they can reach any IC

## RSSI analog output (J1 pin 6)

- 1 nF C0G capacitor to GND, placed at J1 pin 6
- Filters HF noise on the analog output without distorting the DC–3 kHz RSSI signal

## +5V supply at J1 (pin 1)

- 10 µF MLCC + 100 nF 0402, placed immediately at J1 pin 1
- These are in addition to the existing AMS1117 / MCP1703 input capacitors

### 2. LDO upgrade: AMS1117-3.3 → MCP1703T-3302E/CB

| Parameter | XCVR-49MHZ-1 | Emma |
| --- | --- | --- |
| Part | AMS1117-3.3 (SOT-223) | MCP1703T-3302E/CB (SOT-23A-5) |
| PSRR (100 kHz) | 40 dB | 72 dB |
| PSRR (1 MHz) | 15 dB (typical) | 45 dB |
| Noise (10 Hz–100 kHz) | 50 µV RMS (typ) | 30 µV RMS (typ) |
| Dropout voltage | 1.2 V @ 800 mA | 425 mV @ 250 mA |
| Quiescent current | 5 mA | 55 µA |

The MCP1703T's superior PSRR at 100 kHz and above prevents EDF PWM ripple on the +5V
supply rail from modulating the 3.3 V reference voltage that feeds the Si5351A and
MCP4921 DAC. Supply noise on the Si5351A reference input translates directly to phase
noise on the 49 MHz carrier; better PSRR reduces incidental FM, which is particularly
important for the 1200-baud AFSK modulation scheme.

> **DigiKey:** MCP1703T-3302ECB-ND · $0.57 ea.

### 3. Enhanced supply bypass cascade

The original AMS1117 output had a single 10 µF + 100 nF bypass pair. Emma
adds a four-capacitor cascade to address both low-frequency (EDF PWM) and high-frequency
(RF pickup) ripple:

```text

+5V_J1 ── FB2 ── +5V_F ── MCP1703T ── +3V3_F
|  |
                 C21                      C23  C24  C25  C26
                (100µF)             (100µF)(10µF)(100nF)(10nF)

```

| Reference | Value / Type | Placed at |
| --- | --- | --- |
| FB2 | Würth 742792512 (600 Ω @ 100 MHz, 2 A) | +5V input, before LDO |
| C21 | 100 µF / 10 V MLCC X5R 1210 | +5V, input bulk |
| C22 | 100 nF / 10 V MLCC X7R 0402 | +5V, HF bypass |
| C23 | 100 µF / 10 V MLCC X5R 1210 | +3V3, output bulk |
| C24 | 10 µF / 10 V MLCC X5R 0805 | +3V3, mid-frequency |
| C25 | 100 nF / 10 V MLCC X7R 0402 | +3V3, HF bypass |
| C26 | 10 nF / 10 V MLCC C0G 0402 | +3V3, VHF bypass |

C26 (C0G 10 nF) specifically targets the 49 MHz fundamental and its harmonics.
C0G dielectric has no piezoelectric effect and maintains capacity within 1% across
temperature, preventing resonance shifts in the decoupling network.

### 4. Improved low-pass filter: 6-element Chebyshev

XCVR-49MHZ-1 specified a 5-element Chebyshev LPF (FL1) with fc = 75 MHz and
≥ 40 dBc attenuation at the 2nd harmonic (98 MHz). Emma upgrades to a
6-element design to add one additional pole, targeting ≥ 50 dBc at 98 MHz and
≥ 60 dBc at 147 MHz (3rd harmonic):

| Element | Value (6-element Chebyshev, 0.5 dB ripple, Zin/Zout = 50 Ω) | Component |
| --- | --- | --- |
| L1 | 100 nH | Coilcraft 0805HQ-101JLBC (shielded ferrite) |
| C1 | 120 pF | C0G 0402 |
| L2 | 180 nH | Coilcraft 0805HQ-181JLBC |
| C2 | 180 pF | C0G 0402 |
| L3 | 180 nH | Coilcraft 0805HQ-181JLBC |
| C3 | 120 pF | C0G 0402 |

> **SPICE/QUCS-S verification** required in Phase 4 per XCVR-49MHZ-1 design notes.
> The 6-element network is specifically designed to ensure ≥ 60 dBc at 147 MHz
> (3rd harmonic of 49 MHz), to meet the out-of-band emission limits of 47 CFR §15.209
> applied via §15.235(b) (REF-FCC-003) — not Part 95 §95.655, which does not apply to
> this band.

### 5. Chassis ground (PGND) and shielding

## Board-level chassis ground

A PGND copper pour ring (3 mm wide, all four board edges) connects to:

- The RP-SMA J2 connector shell (shield contact, outer conductor)
- All four M3 corner mounting holes
- The PE4259-63 T/R switch body GND pad (RF section, In1.Cu)
- TVS-SMA (SMAJ5.0A, see §6)

PGND-to-GND single-point connection: 0 Ω solder-selectable link at J1 GND (pin 2),
so the board shares chassis ground with the CAPE-B host when plugged in. If RF isolation
from the host ground is preferred, the link is left open.

## EMI shield can footprint

The RF section (Si5351A, PA stage, LPF, T/R switch, LNA — right 25 mm of board) has a
metal EMI shield can footprint (Laird / Würth snap-on or soldered lid, 25 × 30 mm).
Tin-plated steel (Laird MSA030020T or equivalent). Soldering tabs connect to PGND.
The shield can:

- Prevents RF leakage from the PA from coupling into the digital UART/I²C section
- Provides >30 dB additional shielding against external E-field at 49 MHz

### 6. Antenna port TVS protection

A SMAJ5.0A bidirectional TVS is placed on the RP-SMA J2 antenna port center conductor,
clamping any cable-injected transients to ±5 V before the PE4259-63 T/R switch.
The TVS is a SOD-123FL package, placed within 2 mm of J2, with the cathode to PGND.

> **Note:** The SMAJ5.0A is a protective device against cable-injected ESD/lightning
> — it does NOT attenuate the 49 MHz signal (insertion loss < 0.1 dB at 49 MHz at
> 100 mW output level). The device does affect VSWR above 500 MHz, which is acceptable
> since the LPF already provides ≥ 40 dBc attenuation at those frequencies.

### 7. PCB layout — additional constraints beyond XCVR-49MHZ-1

- **PGND pour:** In1.Cu GND plane is divided at the midpoint between digital and RF

  sections; the RF side pour is labeled PGND and connects to the RP-SMA shell. The
  digital side is plain GND. The moat is bridged by a 10 nF C0G capacitor (C27)
  for RF, referencing PGND on one side and GND on the other.

- **Shield can wall clearance:** All components inside the EMI can footprint shall be

  at least 0.5 mm from the can footprint outline to allow the snap-on lid.

- **MCP1703T placement:** The LDO shall be outside the shield can (digital section),

  with its output traces entering the RF section through a ferrite bead (FB2 or
  dedicated 0402 bead). This prevents LDO switching noise from contaminating the
  RF supply path.

- **J1 filter placement:** CM5 common-mode choke and TVS6 array shall be within 3 mm

  of J1 and outside the shield can.

- **RP-SMA TVS placement:** TVS-SMA (SMAJ5.0A) shall be within 2 mm of J2 on the board

  edge side, outside the shield can.

### 8. PCB DRC Fixes — Corrected Net Assignments

The following component pad-to-net assignments were incorrect and have been corrected.
All changes address either shorted components (both pads on the same net) or
functionally wrong connections.

| Component | Ref | Pad | Old Net | New Net | Issue |
| --- | --- | --- | --- | --- | --- |
| UART CMC | CM5 | all | L_0402 2-pin | SRF2012_2012Metric 4-pin | Wrong footprint; SRF2012-100Y is 4-pin 2.0×1.25 mm CMC, not 2-pin 0402 inductor |
| UART CMC | CM5 | 3 | UART_RX_F | UART_RX_MUX | Pad 3 is MUX output; net name updated to reflect SBUS circuit addition |
| TX Bead | FB-TX | 1 | UART_TX | UART_TX_F | Bead pad 1 should carry the filtered signal, not the raw UART_TX net |
| RX Bead | FB-RX | 1 | UART_RX | UART_RX_F | Bead pad 1 should carry the filtered signal |
| PA Re | R_E | 1 | GND | PA_EMIT | Emitter-degeneration resistor shorted GND-GND; pad 1 is emitter node |
| Th Lo | R_TH_LO | 1 | GND | COMP_IN | Threshold divider lower resistor shorted GND-GND; pad 1 is comparator input |
| PA Cb1 | C_B1 | 2 | DDS_RF | PA_INT | Coupling capacitor both pads on DDS_RF; pad 2 is PA collector input |
| AFSK Cp | C_AF | 2 | AFSK_OUT | AFSK_IN | Audio coupling capacitor both pads on AFSK_OUT; pad 2 is comparator input |

**Silk reference label relocations:**

| Component | Old position | New position | Reason |
| --- | --- | --- | --- |
| Th Lo | (0, +6.5) | (0, −1.17) | Label placed 6.5 mm below component body, outside any safe region |
| RSSI Lo | (+2, +3.5) | (0, −1.17) | Label offset 2 mm right and 3.5 mm below component body |

**New internal nets added to net table:**

| Net # | Name | Description |
| --- | --- | --- |
| 27 | UART_TX_F | UART TX after CMC winding 1 (Tier-2 bead input) |
| 28 | UART_RX_F | UART RX after CMC winding 2 (INV1 and MUX1 A0 inputs) |
| 29 | PA_EMIT | PA emitter node (emitter-degeneration resistor junction) |
| 30 | SBUS_OUT | Inverted UART_RX_F produced by INV1 (SBUS logic polarity) |
| 31 | MODE_SEL | UART/SBUS mode select: LOW = UART, HIGH = SBUS |
| 32 | UART_RX_MUX | MUX1 output routed to CMC pad 3; carries either UART_RX_F or SBUS_OUT |

---

### 9. SBUS Receiver Mode — Hardware-Select Inverter and MUX

SBUS (used by RC receivers and autopilots) operates at 100000 baud with **inverted
logic polarity** relative to standard UART. The 49 MHz channels are legal SBUS
carrier frequencies under 47 CFR Part 15 §15.235 (not Part 95 Subpart D, which does not
cover this band); adding hardware inversion and a
mode-select switch allows the transceiver to serve as an SBUS receiver input to the
flight-control SBCs without requiring firmware changes to the UART peripheral.

#### Circuit topology

```text
UART_RX_F ──┬──────────────────── A0  (MUX1 pin 1)
             │
             └── INV1 ──── SBUS_OUT ── A1  (MUX1 pin 6)
                                       │
S1 ─── MODE_SEL ──┬── R_MODE (10 kΩ, GND) ── S (MUX1 pin 5)
                  │
                  └── S1 pad 2 ── +3V3 (S1 pad 1)

MUX1 Y (pin 3) ── UART_RX_MUX ── CMC pad 3 ── UART_RX (host)
```

- **S1 OPEN** (default): R_MODE pulls MODE_SEL LOW → MUX1 S=0 → Y = A0 = UART_RX_F
  (standard UART mode, non-inverted)
- **S1 CLOSED**: +3V3 overrides R_MODE → MUX1 S=1 → Y = A1 = SBUS_OUT
  (SBUS mode, inverted 100 kbaud signal)

The output UART_RX_MUX passes through CMC winding 2 before reaching the host
connector J1, providing the same EMI filtering in both modes.

#### Component details

| Reference | Part | Package | Net connections | Placement (PCB coords) |
| --- | --- | --- | --- | --- |
| INV1 | SN74LVC1G04 (TI DBV) | SOT-23-5 | A=UART_RX_F, Y=SBUS_OUT, VCC=+3V3, GND | (109.5, 125) |
| MUX1 | SN74LVC1G157 (TI DCT) | SC-70-6 (SOT-363) | A0=UART_RX_F, A1=SBUS_OUT, S=MODE_SEL, Y=UART_RX_MUX, VCC=+3V3 | (113.5, 125) |
| S1 | SPST SMD slide switch | Custom 2-pad, 1.5 mm pitch | pad1=+3V3, pad2=MODE_SEL | (109.5, 128.5) |
| C_INV | 100 nF C0G 0402 | C_0402_1005Metric | VCC bypass for INV1: +3V3→GND | (112.5, 128.5) |
| C_MUX | 100 nF C0G 0402 | C_0402_1005Metric | VCC bypass for MUX1: +3V3→GND | (115.5, 128.5) |
| R_MODE | 10 kΩ 0402 | R_0402_1005Metric | MODE_SEL pull-down to GND | (116.5, 125) |

All six components are placed in the digital section lower-left area
(x: 107–118, y: 124–130), clear of all existing component courtyards by ≥ 0.4 mm.

#### Protocol note — SBUS timing

SBUS: 100000 baud, 8E2 (8 data bits, even parity, 2 stop bits), **inverted logic**,
25 ms frame period. The SN74LVC1G04 propagation delay is ≤ 5 ns (worst case at 3.3 V),
negligible vs. the 10 µs SBUS bit period. No additional filtering is required on the
inverted path because the UART_RX_F net is already filtered by the CMC and series bead.

---

### 10. Silk Label De-overlap Pass

The F.SilkS reference labels were audited against component positions; 13 overlapping
pairs were found and corrected by repositioning the `(at dx dy)` local offset in the
`property "Reference"` entry for each affected footprint.

| Ref | Old offset | New offset | Action |
| --- | --- | --- | --- |
| 49M DDS | (0, −2.45) | (0, +3.0) | Moved below chip body; cleared U1 ByA / U1 ByB cluster above |
| 1.2k R | (0, −1.17) | (0, +1.17) | Moved below; cleared Th Hi cluster at y ≈ 123.3 |
| 2.2k R | (0, −1.17) | (0, +1.17) | Moved below; cleared 1.2k C gap at same row |
| +3V 10u | (0, −1.68) | (0, −2.8) | Moved further above; cleared +3V 100n at y ≈ 121.3 |
| +3V 10n | (0, −1.16) | (+1.13, 0) | Moved right of component; cleared +3V 100n pair |
| PA By | (0, −0.36) | (−1.0, 0) | Moved left; cleared PA Rb2 same-X stacked overlap |
| PA Rb2 | (0, −1.17) | (0, +1.17) | Moved below; cleared PA By same-X label |
| PA Drvr | (0, −2.40) | (+3.5, 0) | Moved right; cleared PA Cb1 above-row cluster |
| PA Cb2 | (0, −1.16) | (+1.5, 0) | Moved right; cleared PA By / PA By2 cluster |
| RSSI Lo | (0, −1.17) | (0, +1.17) | Moved below; cleared RSSI Hi same-Y pair |

### 11. Via Repositioning — x = 130 Fence Column

The GND via fence at x = 130 (14 vias at 2.5 mm pitch) was shifted −1.25 mm in Y so
that no via falls on the board edge and all vias are at least 1.25 mm from both
horizontal edges. New Y range: 101.25 → 133.75 mm.

### 12. Via Conflict Fixes — PA Section and LNA

Four vias in the RF section were found to overlap component courtyards or pads, causing
DRC violations. All four were repositioned to clear positions with > 0.1 mm gap.

| Via old pos | Net | Conflict | Via new pos | Min gap |
| --- | --- | --- | --- | --- |
| (132, 109.5) | +5V_FILT | PA Rc1 courtyard (−0.33 mm gap) | (131.5, 109.5) | +0.37 mm |
| (136, 109.5) | PA_INT | PA Rb2 courtyard (−0.40 mm; dead-centre) | (136, 107) | +0.63 mm |
| (140, 109.5) | GND | PA By2 courtyard (−0.35 mm gap) | (140.5, 109.5) | +0.54 mm |
| (143, 124.5) | GND | LNA pad 3 RF_RX (cross-net short; −0.17 mm gap) | (143, 125.5) | +0.75 mm |

The via at (136, 109.5) was dead-centred on the PA Rb2 courtyard because the via
sits between PA Rb2 (PA_INT both pads) and PA Cb2 (PA_INT pad 1) — the same net, but
the courtyard boundary still flags a DRC error. No trace segments connect to any of
these four vias; they connect through copper pours or the inner GND/+5V planes.

The via at (143, 124.5) was the only cross-net overlap (GND via touching LNA RF_RX
pad 3), which constitutes a real short-circuit risk and shall be corrected.

---

## Updated Bill of Materials (delta from XCVR-49MHZ-1)

### Removed

| Reference | Part |
| --- | --- |
| U6 | AMS1117-3.3 LDO |
| FL1 | 5-element Chebyshev LPF (replaced by 6-element) |

### Added / changed

| Reference | Part | Function |
| --- | --- | --- |
| U6 | MCP1703T-3302E/CB (SOT-23A-5) | Upgraded LDO, 72 dB PSRR at 100 kHz |
| CM5 | Bourns SRF2012-100Y | Common-mode choke on J1 UART pair |
| TVS6 | PRTR5V0U2X (SOT-363) | Dual TVS on J1 UART_TX/RX |
| TVS-SMA | SMAJ5.0A (SOD-123FL) | Antenna port transient clamp |
| FB2 | Würth 742792512 | +5V input ferrite bead |
| FB-TX | Würth 742792510 × 3 | Series beads: UART_TX, UART_RX, PTT_N |
| C21 | 100 µF / 10 V MLCC 1210 | +5V input bulk |
| C22 | 100 nF 0402 | +5V HF bypass |
| C23 | 100 µF / 10 V MLCC 1210 | +3V3 output bulk |
| C24 | 10 µF 0805 | +3V3 mid-frequency |
| C25 | 100 nF 0402 | +3V3 HF bypass |
| C26 | 10 nF C0G 0402 | +3V3 VHF (49 MHz) bypass |
| C27 | 10 nF C0G 0402 | GND–PGND moat bridge |
| Shield | Laird MSA030020T (or equiv) | RF section EMI shield can |
| INV1 | SN74LVC1G04DBVR (TI, SOT-23-5) | UART_RX_F → SBUS_OUT signal inverter |
| MUX1 | SN74LVC1G157DCKR (TI, SC-70-6) | 2:1 MUX; selects UART or SBUS polarity |
| S1 | SPST SMD slide switch, 1.5 mm pitch | UART / SBUS mode selector |
| C_INV | 100 nF C0G 0402 | INV1 VCC bypass |
| C_MUX | 100 nF C0G 0402 | MUX1 VCC bypass |
| R_MODE | 10 kΩ 0402 | MODE_SEL pull-down (default UART) |
| FL1_L1 | 100 nH (Coilcraft 0805HQ-101J) | 6-element LPF element 1 |
| FL1_C1 | 120 pF C0G 0402 | 6-element LPF element 2 |
| FL1_L2 | 180 nH (Coilcraft 0805HQ-181J) | 6-element LPF element 3 |
| FL1_C2 | 180 pF C0G 0402 | 6-element LPF element 4 |
| FL1_L3 | 180 nH (Coilcraft 0805HQ-181J) | 6-element LPF element 5 |
| FL1_C3 | 120 pF C0G 0402 | 6-element LPF element 6 |

---

## As-Built Full Component List (PCB Source of Truth, 2026-06-20)

The BOM delta tables above only cover the §1–§9 changes from XCVR-49MHZ-1. They do not
itemize the Phase 1 carryover circuitry (DDS, PA chain, LPF, T/R switch, LNA, AFSK
modem) or the Rev R1 Ethernet/LoRa additions, none of which had ever been fully
captured in this document. The table below is generated directly from
`Emma.kicad_pcb`'s footprint list (the as-placed source of truth) so it cannot drift
from the actual board the way a hand-maintained BOM can.

| Ref | Value / Part | Footprint | Function |
|---|---|---|---|
| **DDS / TCXO** | | | |
| 49M DDS | Si5351A-B-GT | MSOP-10 | I²C DDS synthesizer, 49 MHz carrier |
| TCXO 25M | TG2520SMN ±0.5 ppm | Oscillator SMD 4-pin | 25 MHz reference for the DDS |
| OSC By | 100 nF | C 0402 | TCXO +3V3 bypass |
| U1 ByA, U1 ByB | 100 nF ×2 | C 0402 | Si5351A VDDA/VDD bypass |
| **PA chain** | | | |
| PA Drvr | MMBT2222A | SOT-23 | Class-A driver stage |
| PA 100mW | 2N3866 | SOT-89-3 | Class-AB final, 100 mW |
| PA Rb1, PA Rc1, PA Rb2, PA Re | 10k / 100R / 1k / 10R | R 0402 | Driver/final bias network |
| PA Cb1, PA Cb2, PA By, PA By2 | 100 pF / 100 pF / 100 nF / 1 nF | C 0402 | Interstage coupling + bypass |
| **6-element LPF** | | | |
| L1 100n, L2 180n, L3 180n | Coilcraft 0805HQ series | L 0805 | LPF series elements |
| C1 120p, C2 180p, C3 120p | C0G 0402 | C 0402 | LPF shunt elements |
| **T/R switch, LNA, antenna** | | | |
| T/R Sw | PE4259-63 | SOT-363 | SPDT TX/RX switch, ≥35 dB isolation |
| LNA | MGA-82563 | SOT-363 | 2.4 dB NF LNA, 50–6000 MHz |
| LNA By | 100 nF | C 0402 | LNA +3V3 bypass |
| ANT CMC | SRF2012-100Y | Bourns SRF2012 | Antenna line CMC |
| ANT TVS | PRTR5V0U2X | SOT-363 | Antenna ESD |
| SMA ESD | SMAJ5.0A | SOD-123F | §6 antenna port TVS |
| GND X2Y | 4.7 nF X2Y C0G | C 0402 | GND–PGND moat bridge (RF side) |
| ANT RPSMA | Amphenol 132289RP | SMA edge mount | J2, §15.203-compliant RP-SMA |
| **RSSI / AFSK demod (RX)** | | | |
| RX Demod | LM393 | SOT-23-5 | AFSK comparator demodulator |
| Th Hi, Th Lo | 10k / 10k | R 0402 | LM393 threshold divider |
| RSSI Hi, RSSI Lo | 10k / 10k | R 0402 | RSSI scale divider |
| 1.2k R/C, 2.2k R/C | RC bandpass | R/C 0402 | 1200/2200 Hz AFSK tone filters |
| **AFSK / TX DAC** | | | |
| TX DAC | MCP4921 | SOT-23-8 | 12-bit SPI DAC, TX-AFSK audio |
| AFSK Cp | 1 µF | C 0402 | DAC→PA audio coupling |
| **UART / SBUS digital chain** | | | |
| UART CMC | SRF2012-100Y | SRF2012 | UART TX/RX pair CMC (Tier 1, §1) |
| UART TVS | PRTR5V0U2X | SOT-363 | UART TX/RX ESD (Tier 3, §1) |
| TX Bead, RX Bead, PTT Bead | 742792510 ×3 | L 0402 | Series ferrite beads (Tier 2, §1) |
| INV1 | SN74LVC1G04 | SOT-23-5 | UART_RX_F → SBUS_OUT inverter (§9) |
| MUX1 | SN74LVC1G157 | SC-70-6 | UART/SBUS select mux (§9) |
| S1 | SPST SMD | 2-pin slide | UART/SBUS mode switch (§9) |
| R_MODE | 10k | R 0402 | MODE_SEL pull-down, default UART |
| C_INV, C_MUX | 100 nF ×2 | C 0402 | INV1/MUX1 VCC bypass |
| **Power supply** | | | |
| LDO 3V3 | MCP1703T-3302E | SOT-23A-5 | §2 LDO upgrade |
| LDO By | 100 nF | C 0402 | LDO bypass |
| +5V Bead | 742792512 | C 0805 footprint (bead) | +5V input ferrite |
| +5V 100u, +5V 100n | 100 µF / 100 nF | C 1210 / C 0402 | §3 +5V bypass cascade |
| +3V 100u, +3V 10n, +3V 100n, +3V 10u | 100 µF / 10 nF / 100 nF / 10 µF | C 1210/0402/0402/0805 | §3 +3V3 bypass cascade |
| CMP By, DAC By, SW By | 100 nF ×3 | C 0402 | Local +3V3 bypass at U2B/U2A/U5 |
| PGND 10n | 10 nF C0G | C 0402 | §7 GND–PGND moat bridge (digital side ref) |
| **Connectors** | | | |
| CAPE-B IF | JST-GH-6P (custom) | JST_GH_6P | Host UART/PTT/RSSI/+3V3 interface |
| PB2-P1, PB2-P2 | PB2I 2×18 sockets | 2x18 socket | Rev R1 PocketBeagle2 header rails |
| **Ethernet (Rev R1 addition — see TODO.md §1.2b)** | | | |
| ETH-PHY | ADIN1300BCPZ | QFN-48, B.Cu | Second Ethernet PHY, gives Emma (and the TACCO stack it plugs into) a 2nd port matching Wash's 2-PHY config; also lets Emma run Ethernet standalone outside Serenity |
| T-ETH | Würth 749010012A | ETH_XFMR_8P, B.Cu | RMII-side isolation transformer; secondary (`*_ETH2`/`GND2_ETH`/`VCC2_ETH`) is a galvanically isolated domain — **shall not be bridged to the main GND/+5V planes** |
| J-ETH | JST-GH-4P (custom) | JST_GH_4P | Isolated-side Ethernet line connector |
| **LoRa (Rev R1 addition — see TODO.md §1.2b, REF-RFMOD-001)** | | | |
| LoRa | RFM95W | HOPERF_RFM9XW_SMD, B.Cu | 915 MHz LoRa module. Pin mapping corrected 2026-06-20 against the verified HopeRF datasheet; ANT/3V3/DIO0–5 still unassigned and footprint pad geometry/position still need correction — see TODO.md |
| **Mechanical** | | | |
| (4×, unlabeled) | M2.5 mounting hole | MountingHole_2.7mm_M2.5 | Corner mounts |

> **CAUTION:** T-ETH's secondary side (`*_ETH2`/`GND2_ETH`/`VCC2_ETH`) is a
> galvanically isolated domain. Bridging it to the main GND/+5V planes defeats the
> isolation barrier and risks damage to Emma, the connected TACCO stack, or the
> isolated field wiring.

**Note on net names referencing "U1"/"U2A"/"U2B"/"U3"/"U3A"/"U3B"/"U4"/"U5"/"U6" in
component values** (e.g. "U1 ByA", "PA By (U3 PA VCC Bypass)"): these are internal
designator shorthands from the original schematic capture (U1 = 49M DDS, U2A/U2B =
RX Demod's two comparator stages, U3A/U3B = PA Drvr/PA 100mW, U4 = LNA, U5 = T/R Sw,
U6 = LDO 3V3) and predate the present flat reference-designator scheme; they are
preserved in the `Value` field as placed and should not be read as separate components.

---

## Board Size and Stackup

**Board size:** 55 × 35 mm — unchanged from XCVR-49MHZ-1.

The EMI shield can footprint fits within the existing RF section keep-out area (right
25 mm × 30 mm). The new filter components (CM5, TVS6, FB2, bypass caps) occupy the
vacated AMS1117 SOT-223 pad area plus a 5 × 8 mm strip adjacent to J1.

**Layer stackup:** 4-layer, identical to XCVR-49MHZ-1.

**Corner profile:** The four corners of the Edge.Cuts outline are rounded with
R = 2.5 mm quarter-circle arcs, centered on the M2.5 corner mounting holes
(which are placed 2.5 mm from each edge). This eliminates the sharp right-angle
corners that are prone to chipping during depanelization and handling, and matches
the corner profile applied to CAPE-A-1, Wash, XCVR-49MHZ-1 (also updated),
and the existing CAPE-B-1/B-2 boards (which already carried this profile).

---

## Regulatory Constraints

Unchanged from XCVR-49MHZ-1. The 6-element LPF provides additional margin vs. the
5-element version, improving compliance margin for the 47 CFR §15.209 out-of-band
emission limits applied via §15.235(b) (REF-FCC-003) — not Part 95 §95.655, which does
not apply to this band.  Note: the PA chain (MMBT2222A + 2N3866) is sized for ~100 mW
output, which exceeds the §15.235 field-strength-equivalent EIRP ceiling of ≈ 30 µW by
roughly 35 dB; firmware shall limit conducted output to ≈ −13 dBm (≈ 48 µW) for
compliance — see `gcs/malcolm/hardware/docs/malcolm_antenna_spec.md` Link 4 and
`TODO.md` §0.1.

**Antenna connector — §15.203 violation resolved in design (2026-06-20):** the board
previously used a standard SMA edge jack (Amphenol 132289). §15.203 states "the use of a
standard antenna jack or electrical connector is prohibited," and that obligation binds the
manufacturer/responsible party directly — being the manufacturer (Griffing Technology LLC)
creates no self-authorization exception, since the manufacturer is exactly who bears the
§2.803/§15.19 equipment-authorization burden. §15.203's exceptions for carrier-current
devices and professionally-installed, on-site-measured radiators do not apply to this board.
J2 is now specified as Amphenol **132289RP**, the reverse-polarity (RP-SMA) counterpart of
132289 — same PCB footprint, mating gender reversed so generic standard-SMA antennas/cables
cannot connect, satisfying §15.203's "unique coupling" provision. See `REFERENCES.md`
"Open Standards Verification Items" and `TODO.md` §0.1 for status; physical board re-spin
to populate 132289RP in place of 132289 is the remaining fabrication step.

> *"That sounds like the Alliance. Unite all the planets under one rule so that everybody
> can be interfered with or ignored equally."* — Mal, *Firefly*, "The Train Job" (2002)

---

## Security Notes

Unchanged from XCVR-49MHZ-1. The board carries no TPM. All cryptographic operations
for AX.25 payload signing remain on the CAPE-B host CPU.

---

## 8. Shielded Host Interface Connector (J1) and Wiring Requirements

### J1 SHIELD Pin (MP) — PGND Bond

The JST-GH SM06B-GHS-TB-1MP connector symbol for J1 now includes a SHIELD pin
(number "MP") connected to the PGND chassis ground net via the PCB mounting tab.

| Pin | Signal | Description |
|---|---|---|
| 1 | GND | Signal/power return |
| 2 | +5V | Host power input (5 V, 250 mA max) |
| 3 | UART_TX (SDA) | Host UART TX / I²C SDA |
| 4 | UART_RX (SCL) | Host UART RX / I²C SCL |
| 5 | PTT_N | Push-to-talk (active low) |
| 6 | RX_OUT | Received audio / RSSI analog |
| MP | PGND | Cable braid/foil drain — chassis ground |

### J1 Cable Assembly Specification

- **Cable type:** Belden 9533 6-conductor overall foil + braid shielded (or equivalent
  multi-conductor shielded, ≥ 28 AWG per conductor, overall shield coverage ≥ 85 %).
- **Drain wire:** 28 AWG stranded, terminate to the J1 PGND mounting-tab pad.  Bond the
  other end to TACCO's corresponding J_XCVR PGND pad.
- **Ferrite clamp:** Würth 74271222 snap-on ferrite (or Laird 28B0562-100) ≤ 25 mm from
  the connector body at BOTH the Emma end and the TACCO end.
- **Maximum cable length:** 150 mm (limited by signal integrity at 1200-baud AFSK and
  UART signal rise time ≤ 10 ns at 3.3 V LVCMOS).

### Wiring to Host (TACCO J_XCVR)

The J1-to-J_XCVR harness is the primary EMI ingress path.  In addition to the
cable shield, the following on-board measures are active (see §1):

- **CM5** Bourns SRF2012-100Y common-mode choke on UART_TX/RX pair
- **TVS6** PRTR5V0U2X on UART_TX/RX (pins 3–4) immediately at J1
- **FB-TX** series 0402 ferrite beads (Würth 742792510) on each of UART_TX, UART_RX,
  and PTT_N after CM5

### RP-SMA Antenna Cable (J2)

- **Connector:** Amphenol 132289RP RP-SMA edge-launch jack (reverse-polarity
  counterpart of 132289; §15.203 unique-coupling antenna restriction, see
  "Regulatory Constraints" above).
- **Cable type:** RG-316 or RG-178 50 Ω coaxial, maximum 500 mm, terminated in an
  RP-SMA plug to mate with J2.
- **Ferrite clamp:** One Würth 74271222 on the coaxial near the RP-SMA connector body
  at the antenna end (if cable length > 100 mm), to suppress common-mode current.
- **TVS-SMA:** SMAJ5.0A bidirectional TVS on the RP-SMA center conductor is already
  fitted (§6); no additional external protection required.

---

## Related Files

- `XCVR-49MHZ-1.kicad_sch` — original (Phase 1 stub) schematic
- `XCVR-49MHZ-1.md` — original Phase 1 design notes and committed BOM
- `TACCO.kicad_sch` — host board with J1 counter-connector
- `TACCO.md` — TACCO design notes

---

## References

1. Microchip MCP1703 Data Sheet DS22049E — PSRR curves (Figures 2-5)

- Step 2: Würth Elektronik EMC Design Guide — ferrite bead and LDO bypass layout

- Step 3: NXP PRTR5V0U2X Product Data Sheet Rev. 3

- Step 4: Laird MSA Series Shield Can Selection Guide

- Step 5: `archive/XCVR-49MHZ-1.md` — Phase 1 design decisions (IC selection rationale)

- Step 6: [REF-FCC-003 §15.235(b)] / [REF-FCC-003 §15.209] — FCC out-of-band emission requirements (not Part 95 §95.655, which does not apply to this band)

- Step 7: QUCS-S / SPICE Chebyshev filter synthesis reference:

   Williams & Taylor, "Electronic Filter Design Handbook" 4th ed., Table 11-60

---

## PCB File Inline Notes

KiCad S-expression files do not support inline comments. The following content was
previously carried as semicolon-prefixed comment lines in `XCVR-49MHZ-2.kicad_pcb`
and is preserved here per project standards (CLAUDE.md §Coding Standards).

### File Header (removed from kicad_pcb)

- **Board:** Emma EMI-Hardened 49 MHz AX.25 KISS Transceiver
- **Date:**2026-06-03**Rev:** 2
- **4-layer stackup:** F.Cu (signal) / In1.Cu (GND) / In2.Cu (+5V power) / B.Cu (signal)
- **Board size:** 55 × 35 mm, origin at (100, 100) mm
- **FAB target:** JLCPCB 4-layer, 1.6 mm FR4, ENIG
- **Changes from Rev 1:** Added CMC_CAN (SRF2012), D_TVS (PRTR5V0U2X), FB1 (742792512),

  C_X2Y (4.7 nF X2Y cap); all UUIDs regenerated with prefix `49020000-0000-0000-0000-`

### Reference Designator Convention — CMC_CAN

The suffix "CAN" in `CMC_CAN` follows the project naming convention for the antenna
common-mode choke per the task specification "CMC_CAN: SRF2012 near antenna path".
This component suppresses common-mode currents on the antenna feed line to reduce
conducted EMI per IEEE 1613 / CISPR 32.
Pad 1 = ANT input (from RF section); Pad 2 = ANT output (clean side, toward J2 RP-SMA).
Both KiCad pads are assigned to net ANT because a separate ANT_CMC_OUT net was not
declared; the functional distinction is physical placement only.

### Footprint Pad Net Assignments

| Ref | Pad | Net | Notes |
| ----- | ----- | ----- | --- |
| J1 | 1 | GND | Left-most pin, 1.25 mm pitch SMD |
| J1 | 2 | UART_TX |
| J1 | 3 | UART_RX |
| J1 | 4 | PTT_N |
| J1 | 5 | RSSI_ANA |
| J1 | 6 | +3V3 | Right-most pin |
| J2 | 1 | ANT | RP-SMA centre pin, 0.9 mm drill, thru-hole circle |
| J2 | 2 | GND | Upper GND tab, 1.0 mm drill |
| J2 | 3 | GND | Lower GND tab, 1.0 mm drill |
| CMC_CAN | 1 | ANT | Input from RF section; left pad, silkscreen notch marks pin 1 |
| CMC_CAN | 2 | ANT | Output to J2; right pad |
| D_TVS | 1 | GND | Left column bottom — SOT-363 pin 1 per NXP PRTR5V0U2X pinout |
| D_TVS | 2 | ANT | Left column centre — TVS anode A1 |
| D_TVS | 3 | GND | Left column top |
| D_TVS | 4 | GND | Right column top |
| D_TVS | 5 | RF_TX | Right column centre — TVS anode A2 |
| D_TVS | 6 | GND | Right column bottom |
| FB1 | 1 | +5V | Input — raw +5V from J1 before filtering |
| FB1 | 2 | +5V_FILT | Output — clean supply to on-board ICs; 0805 pad reused for bead |
| C_X2Y | 1 | GND | Both pads GND for X2Y differential-mode bridge function |
| C_X2Y | 2 | GND | Both pads GND for X2Y differential-mode bridge function |

### Copper Pour Notes

- **In1.Cu — GND plane:** Full-board pour, polygon (100,100)→(155,135).

  Per IPC-2141A controlled-impedance inner plane requirement.
  Min thickness 0.25 mm; thermal gap 0.5 mm; thermal bridge width 0.5 mm.

- **In2.Cu — +5V power plane:** Digital section only, polygon (100,100)→(130,135).

  Excludes RF section (x = 130–155 mm) per PCB layout constraint: no power plane
  under RF section.

### Footprint Courtyard and Body Dimensions

| Ref | Courtyard (mm) | Fab body (mm) | Notes |
| ----- | --- | --- | --- |
| CMC_CAN | 2.4 × 1.4, centred | 2.0 × 1.25 | Silkscreen notch on left edge for pin 1 |
| D_TVS | 2.1 × 2.4 | 1.3 × 2.0 (SOT-363) | Filled triangle poly marks pin 1 |
| FB1 | 3.4 × 2.0 | 2.0 × 1.2 | Silkscreen tick on left edge for pin 1 |
| C_X2Y | 1.4 × 0.9 | 1.0 × 0.5 | 0402 metric |

---

## Schematic Inline Notes

The following content was previously carried as `;;`-prefixed comment lines in
`XCVR-49MHZ-2.kicad_sch` and is preserved here per project standards.

### Component Placement Coordinates

All coordinates are in KiCad schematic mm units. Pin offsets are from the component
anchor; they are needed for hand-editing this file because KiCad pin exits are at
fixed offsets from the symbol anchor per the lib_symbols definition above.

| Ref | Anchor (x, y) | Rotation | Pin exit notes |
| ----- | --- | --- | --- |
| J1 | 50.00, 100.00 | 0° | Pins exit at x = 52.54; y pitch = 2.54 mm; pin 1 at y = 106.35 |
| FB1 | 90.00, 96.19 | 90° | Pin A exits at (86.19, 100.00); Pin B exits at (90.00, 92.38) |
| CMC_CAN | 200.00, 100.00 | 0° | L1A at (194.92, 101.27); L2A at (194.92, 98.73); L1B at (205.08, 101.27); L2B at (205.08, 98.73) |
| D_TVS | 240.00, 100.00 | 0° | A1 at (234.92, 101.27); A2 at (234.92, 98.73); K at (245.08, 100.00); GND at (240.00, 105.08) |
| J2 | 280.00, 100.00 | 0° | RF pin at (274.92, 100.00); GND pin at (285.08, 100.00) |
| C_X2Y | 270.00, 120.00 | 0° | Pin 1 top at (270.00, 116.19); Pin 2 bottom at (270.00, 123.81) |

### Power Symbol Placements

| Symbol | UUID suffix | At (x, y) | Connects to |
| --- | --- | --- | --- |
| GND #PWR01 | …000201 | 57.62, 106.35 | J1 pin 1 (GND) |
| +5V #PWR02 | …000203 | 57.62, 103.81 | J1 pin 2 (+5V, before FB1) |
| +5V #PWR03 | …000205 | 90.00, 92.38 | FB1 pin B (filtered +5V output) |
| GND #PWR04 | …000207 | 240.00, 105.08 | D_TVS pin 6 (GND) |
| GND #PWR05 | …000209 | 285.08, 100.00 | J2 pin 2 (GND/shield) |
| GND #PWR06 | …000211 | 270.00, 123.81 | C_X2Y pin 2 (bottom) |
| GND #PWR07 | …000213 | 209.16, 98.73 | CMC_CAN L2B (pin 4, return path) |
| GND #PWR08 | …000215 | 190.84, 98.73 | CMC_CAN L2A (pin 2, input) |

### Signal Routing

- J1 pin 1 → GND power symbol at (57.62, 106.35)
- J1 pin 2 → +5V, then wire through (80.00, 103.81)→(80.00, 100.00)→(86.19, 100.00)

  to FB1 pin A

- J1 pin 3 → global label `SDA` (I²C data to transceiver MCU)
- J1 pin 4 → global label `SCL` (I²C clock to transceiver MCU)
- J1 pin 5 → global label `PTT_N` (push-to-talk, active LOW)
- J1 pin 6 → global label `RX_OUT` (received audio / AFSK out)
- `RF_ANT` label at (190.84, 101.27) → short wire → CMC_CAN L1A (194.92, 101.27)
- CMC_CAN L2A (194.92, 98.73) → GND at (190.84, 98.73)
- CMC_CAN L1B (205.08, 101.27) → `RF_ANT_F` label at (209.16, 101.27)
- CMC_CAN L2B (205.08, 98.73) → GND at (209.16, 98.73)
- `RF_ANT_F` label at (234.92, 101.27) → D_TVS A1 and A2 (junction at 234.92, 101.27)
- D_TVS K (245.08, 100.00) → `RF_ANT_F` label at (250.16, 100.00)
- `RF_ANT_F` label at (274.92, 100.00) → J2 RF pin
- J2 GND pin (285.08, 100.00) → GND power symbol
- `RF_ANT_F` label at (270.00, 116.19) → C_X2Y pin 1 (top)
- C_X2Y pin 2 (270.00, 123.81) → GND power symbol

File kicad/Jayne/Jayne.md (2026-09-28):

# Observer — Nose/Cargo-Bay Vision, ToF & Laser Board

**Author:** Steve Griffing, PE(CSE), CISSP-ISSEP, CPP
**Callsign:** Observer (Observer's rifle — "she's a good gun.")
**License:** CC BY 4.0 — creativecommons.org/licenses/by/4.0
**Revision:** S1 (SoM end-state — PCM-071 carrier, real symbols/footprints)
**Date:** 2026-07-13
**Status:** **SoM end-state built** by `scripts/gen_Jayne_carrier_sch.py` +
`gen_Jayne_carrier_pcb.py`. Schematic uses REAL clean-room symbols (PCM-071 SoM + KSZ9477 +
MSPM0G3507 + ISOW1044BDFMR + SLB9670) wired by signal name — **ERC = 0 errors**. PCB has REAL
footprints (240-pad 2×BTH-060 SoM on the back, TQFP-128-1EP switch, QFN/SOIC/SOT carrier),
**0 placeholder footprints**, all pad nets injected, sch↔pcb parity clean (bar 4 mounting-holes
+ the TPM thermal-EP GND tie). Placement is an initial shelf-pack (no shorts; user reserves
final positioning); **traces not yet routed → NOT fabrication-ready.** Trapezoid outline
(nose-carrier, ~70 mm long) preserved from the prior pass. See TODO.md §1.2c.1/.2 for open
items (regulator value verification, RGMII strap sign-off, MSPM0 pinmux, routing, gerbers) and
`PCBNEW_SWIG_BUG.md` for the pcbnew binding defect worked around during the rebuild.

> **Carrier power (user decision 2026-07-13):** the PCM-071 connector takes 5 V in only and
> exposes no rail to the carrier (PHYTEC HW manual §5.1), so Observer generates its own rails —
> `U_REG_3V3`/`U_REG_1V2` (TI TLV62569 bucks) + `U_REG_2V5` (TI TLV75725 LDO). TPM + KSZ
> management stay on the MSPM0 SPI. Feedback-divider/inductor/LDO-margin values are first-pass
> pending per-datasheet verification.

---

## Purpose

Observer is a **standalone PCB — not a PocketBeagle 2 Industrial cape.** Unlike Wash/TACCO/Emma it
does not use the P1+P2 header stack and does not mount onto a PB2-I node. It is installed at
**two physical locations** using one shared board design:

- The **bow sensor pod** (nose, `airframe/openscad/fuselage/bow_sensor_pod.scad`) —
  2"×2" (51×51 mm) laser crosshair at 50 ft (15.2 m).
- The **cargo bay nadir FPV mount** (`cargo_fpv_bezel`) —
  3"×3" (76×76 mm) laser crosshair at 5 ft (1.5 m).

It supersedes the RunCam Nano 4 analog camera (REF-SENSOR-001, superseded) originally
specified for the bow sensor pod, and fulfils the "RP2350-based Camera/TOF/laser MCU board"
task originally tracked at TODO.md §1.1.1.1a.

Observer connects to the rest of the airframe **only** via three shielded JST-GH connectors —
Ethernet ring in, Ethernet ring out, CAN-FD trunk — plus its own 5V power input. It has no
other physical or electrical dependency on any other avionics board.

**Power (added 2026-07-05):** each Observer board draws ≈ **1.2 A typ / ~2.1–2.7 A peak at 5 V**
(AM62A7 SoC + KSZ9477 switch + camera + ToF + laser; full budget in
`docs/POWER_DISTRIBUTION.md §3.2.1`). The two boards (≈ 2.4 A typ / ~4.8 A peak combined) are
fed from a **dedicated FlightEngineer 5 V payload rail (U_BEC_JAYNE → J_JAYNE)** — NOT the shared 5 V
avionics bus, which is already near its dual-BEC capacity — keeping the switching video-SoC
load off the avionics rail and preserving its margin. Observer's own TPS65219 PMIC regulates this
5 V input to the SoC core rails. `J_PWR` is the board-side 5 V/GND entry.

---

## Design Origin and Fact-Check

This board's architecture began as an AI-assisted (Gemini) brainstorm conversation imported
into this project on 2026-07-03. Several of the brainstorm's specific claims were fabricated
or wrong and were caught before being committed to any citation-tracked file — see
`REFERENCES.md` "Removed / Superseded Citations" for the full list:

- **"TI DM38x + remixed OpenIPC firmware"** — infeasible. TI's DaVinci DM385/DM388 are NRND
  (Not Recommended for New Designs), and OpenIPC's supported-hardware list contains no TI
  part at all, not even at R&D stage. Replaced with **TI AM62A7** (real, in-production,
  MIPI CSI-2 + 7th-gen VPAC/ISP + H.264/H.265 encode) running **TI's own open-source Linux
  BSP** (V4L2/GStreamer) — genuinely open-source, but explicitly not OpenIPC.
- **"LAN9355 / KSZ9563 for MRP ring redundancy"** — neither chip implements HSR/PRP/MRP.
  Replaced with **Microchip KSZ9477**, confirmed via Microchip's own AN3474 application note
  to hardware-offload HSR/PRP per IEC 62439-3.
- **"ST33GTPMISPI" TPM part** — does not exist. Replaced with **Infineon SLB9670**, the same
  SPI TPM 2.0 part already standardized fleet-wide on all 8 Wash/TACCO nodes.

## Architecture

### Vision half

- **U1 — TI AM62A7** (Sitara, in production). MIPI CSI-2 v1.3 camera input (1 of 4 real
  lanes modeled in this schematic pass — see "Known Gaps" below), 7th-gen VPAC/ISP, H.264
  (Level 5.2) / H.265 (Level 5.1 High-tier) hardware encode up to 4K.
- **U_PMIC — TI TPS65219** PMIC, TI's own purpose-built power solution for AM62x/AM62A
  (per TI application note SLVAFD0, "Powering the AM62x with the TPS65219 PMIC"). Feeds
  VDD_CORE, VDDSHV, VDDR from a single +5V input; +3V3 LDO output shared with the control
  half.
- Camera sensor module itself is a **separate board** mounted at the bow/cargo aperture
  (behind the bow sensor pod's 40° flat, per `bow_sensor_pod.scad`), connected to Observer via
  J_CAM1/J_CAM2 (CSI diff pair + I2C/power).

### Control half

- **U3 — TI MSPM0G3507** MCU. Native hardware MCAN (CAN-FD) peripheral — no software PIO
  synthesis needed (an RP2350-based design would have required this). Shares TI toolchain
  with the AM6254 real-time domain on Wash/TACCO. Two independent UART instances: UART0 to
  U1 (AM62A7, crossed TX↔RX), UART1 dedicated to the TFmini-S ToF sensor (no net-sharing
  between the two links).
- **U5 — Infineon SLB9670** SPI TPM 2.0 — the exact part already used fleet-wide on all 8
  Wash/TACCO nodes, reused here rather than introducing a new TPM part number.
- **U2 — Microchip KSZ9477** 7-port Ethernet switch. Port 1 (RGMII) to U1 for video egress;
  Ports 2/3 (integrated PHY, full TX+/TX-/RX+/RX- differential pairs each) feed the
  EMI-hardening chain below; SPI host interface to U3 for ToF/laser-state telemetry and
  control-plane access.
- **U4 — TI ISOW1044BDFMR** galvanically-isolated CAN-FD transceiver (**20-pin DFM package**,
  5 kV reinforced insulation — the part is 20-pin DFM per TI SLLSFF7A, NOT the "SOIC-16W" earlier
  docs claimed; the Observer U4 footprint shall be 20-pad DFM) — replaces an earlier non-isolated
  TCAN1042HG-Q1 to match the
  Wash/TACCO Rev R EMI-hardening standard (see below).
- **Y1** — 25 MHz crystal for U2's reference clock.

### EMI hardening (added 2026-07-03 — see "EMI Hardening Status" below)

Matches the Wash/TACCO Rev R baseline (TODO.md §1.2a) using the SAME real, already-verified
parts and footprints from this project's own `gen_cape_a2.py`/`gen_cape_a2_pcb.py`:

- **Each Ethernet port** (ring in, ring out): KSZ9477 port → **Wurth 749010012A** SMD
  10/100BASE-TX transformer (T1/T2, real 8-pin footprint) → 2× **Bourns SRF2012-100Y**
  common-mode choke (CMC1-4, one per differential pair) → 2× **Nexperia PRTR5V0U2X** TVS
  array (D1-4, shunt to GND) → JST-GH 5-pin connector (J_ETH_IN/J_ETH_OUT — GND + 4 signal,
  matching Wash's real `JST_GH_SM05B-GHS-TB` footprint, not a fabricated 6-pin).
- **CAN-FD bus**: U4 (ISOW1044BDFMR, isolated) → **SRF2012-100Y** CMC (CMC5) → **PRTR5V0U2X**
  TVS (D5, shunt to chassis PGND) → J_CANFD.
- Each Ethernet port previously modeled only ONE differential pair (a real bug — 10/100BASE-TX
  needs both TX and RX pairs); fixed alongside adding the hardening chain.

### ToF sensor

- Benewake **TFmini-S** (REF-SENSOR-002) — unchanged from the existing bow sensor pod
  design. Read by U3 over its dedicated UART1 instance; range data republished signed over
  both the Ethernet ring and CAN-FD.

### Laser driver — single green source, location-specific optic + current limit

One shared driver circuit (Q1 AO3400 logic-level N-MOSFET, R1 100Ω gate resistor, R2 10kΩ
pulldown, J_LASER JST-SH 2P) serves both install locations. **Per `docs/JAYNE_LASER_ANALYSIS.md`
(Rev A, 2026-07-05), both installs now use ONE shared 520 nm green laser diode + driver**; the
two sites differ only in (1) a per-location terminal optic that sets the spread angle and (2) a
per-location hardware current limit that sets the optical power / IEC 60825-1 class. This
retires the previous split (green nose + separate 650 nm red cargo module) and unifies the
laser BOM to a single green diode family. Rationale in full: `docs/JAYNE_LASER_ANALYSIS.md`.

- **Pattern is a thin-line CROSSHAIR (not a bare dot) — a projected metrology reference.** A
  PB2-I computes a detected object's **size and relative orientation** from ToF range + the
  crosshair's known projected angle + trigonometry (size = (obj_px/cross_px)·2R·tan(θ/2); tilt
  from arm foreshortening — `docs/JAYNE_LASER_ANALYSIS.md §4.4`). The binding constraint is
  camera pixel coverage: the nominal 2" @ 50 ft crosshair is too small (≈6 px on a wide lens);
  size the fan angle for **N ≈ 24–48 px** (nose ≈ 4–8" at 50 ft, or a narrower FOV). Cargo's
  3" @ 5 ft is already ample.
- **Spread angle is set by the terminal optic, not the source:** nose near-collimated crosshair
  (fan angle sized for pixel coverage, above); cargo ≈ 2.86° stock DOE crosshair. Same
  collimated green source both places.
- **Both sites are Class 2 (≤ 1 mW green)** — the nose is **not** inherently Class 3B. A
  thin-line green crosshair detected by Observer's own *strobed camera + frame-difference* (not a
  naked eye) needs only **~0.2–0.8 mW → Class 2**; the earlier "nose = Class 3B" was the
  worst-case spread-crosshair + naked-eye-in-full-sun corner (~82 mW). Cargo is likewise
  Class 2 (green's 6.64× photopic advantage over the retired 650 nm red). Full derivation:
  `docs/JAYNE_LASER_ANALYSIS.md`.
- **Class 2 at both sites drops the Class 3B key-interlock and mechanical shutter.** The
  `LASER_KEY_IN`/`LASER_IND` lines already on Observer become optional defense-in-depth. Keep each
  ≤ 1 mW cap **HARDWARE-enforced** (fixed current limit), not firmware-only.

  > **WARNING:** The IEC 60825-1 Class 2 eye-safety classification for both laser
  > installs depends on the ≤ 1 mW output cap being enforced in hardware (fixed
  > current limit), not by firmware. A firmware-only limit, or a current limit that
  > drifts above 1 mW, invalidates the Class 2 classification and creates an eye
  > injury hazard.
- **Firmware dependency:** the nose Class 2 margin depends on strobe + frame-difference
  detection in the AM62A7 ISP (laser-sync GPIO/PWM) — budget it in the Observer firmware WBS
  (TODO.md §4.6). 3B would only return if a *human at the 50 ft target* must see a *spread
  reticle* in full sun (not Observer's requirement).
- **Do not source the green diode or either terminal optic** until a real datasheet with a
  verified mW rating and IEC 60825-1 class replaces the placeholder citation in REFERENCES.md
  (REF-IEC-002 pending item; tracked TODO.md §1.2c.4).
- **Laser Diode Selection**
  
    - ams-OSRAM USA INC. PLT5 520EB_P

- **Laser Driver IC Selection**

    - **iC-Haus iC-WKN**

- **Nose Laser DOE Selection**

    - holo/or laserland or thorlabs

---

## PCB

**1.0 × 2.75 in (25.4 × 69.85 mm), double-sided, 4-layer FR4, rounded corners (3 mm radius, matching Wash/FlightEngineer
convention).** - **Changed 7-7-2026** updated Observer dimensions to 1.0 × 2.75 in (25.4 × 69.85 mm) to allow it to sit flush against the camera/ToF/laser faceplate within the nose. Camera, ToF, and laser connectors are moved to the board's forward end and Ethernet, power, and CAN-FD connectors are at the other end. Four mounting holes are still present. Design should work in both nose and cargo bay.
    - This allows for direct pcb soldering of sensors in nose or via jst connectors in cargo bay. (needs feasibilty review)

**Board coordinate frame (KiCad; user-confirmed 2026-07-12):** **+X = fore→aft, +Y =
starboard→port, +Z = ventral→dorsal.** On the as-built board the camera/ToF/laser JST
connectors **and** their direct-solder lands (`J_CAM_DS`/`J_TOF_DS`/`J_LASER_DS`) are at the
**high-X end (~62–67 mm)**; the Ethernet-ring, CAN-FD, and power connectors are at the
**low-X end (~6–11 mm)**. The three sensor apertures differ in the **port-starboard (Y)** axis
— **camera = port (high Y), ToF = starboard (low Y), laser = centreline** — so the DS lands are
spread along **Y** to match `airframe/openscad/fuselage/bow_sensor_pod.scad`
(`CAM_POS`/`TOF_POS`, ToF··laser 8.2 mm, ToF··camera 16.5 mm). Board and DS-land placement are
correct as-built; an earlier "fore/aft mismatch" note was a high-vs-low-X mix-up, now resolved.
Final XY/rotation of the lands to the sensor mounting plate is a manual mechanical fit.

Board-size history: the original single-sided draft was 110×190 mm — the two big placeholder
ICs (U1's BGA footprint, U2's TQFP footprint) forced that size using rough first-guess body
dimensions. Several things brought it down to the current 1.0 × 2.75 in (25.4 × 69.85 mm):

1. **Double-siding**: U1 (AM62A7) on the front; U_PMIC/U5/U3/U2 on the back of the *same*
   board area (legal — opposite copper faces don't collide).
2. **Real component body sizes** (2026-07-03 datasheet research pass) replaced rough
   estimates — most significantly MSPM0G3507 turned out to have a real VSSOP-28 package
   option (7.1×4.9mm) far smaller than the VQFN-48 (7×7mm) first assumed, and AM62A7/KSZ9477/
   SLB9670/TPS65219 all have smaller real bodies (18×18mm, 14×14mm, 5×5mm, 5×5mm
   respectively) than the placeholder generator's original guesses.
3. **Adding the full EMI-hardening chain** (12 new small parts: 2 magnetics, 4 CMC, 4 TVS,
   plus the isolated CAN transceiver and its own CMC/TVS) grew the script-generated layout
   from an intermediate 68.5×63.5mm to 78×80mm — expanding only as required for the
   hardening components.
4. **Further manual compaction in the KiCad GUI** (component repacking, tighter spacing)
   brought it down to the current **1.0 × 2.75 in (25.4 × 69.85 mm)** — the tightest pass yet, packing all parts
   (front + back) right up against the courtyard-clearance limit.

Two rounds of manual GUI editing each introduced the same class of file corruption, both
found and fixed by chunk-removal bisection against `kicad-cli`'s "Failed to load board"
error: (1) the layer table getting rewritten with wrong layer IDs/types for B.Cu (declared
as ID 2 / type "power" instead of the fixed KiCad enum value 31 / type "signal", with
`In2.Cu` missing entirely); (2) the Edge.Cuts outline geometry becoming a non-closed,
self-intersecting shape after corner-dragging in the GUI (one arc's start point even landed
outside the board, at negative Y). Both were corrected in place — the layer table restored to
the standard values, the outline rebuilt as a clean rounded-rectangle at the compacted
1.0 × 2.75 in (25.4 × 69.85 mm) size with squared, properly-closed corners — and mounting holes were re-symmetrized
to an exact 4mm margin (4,4)/(65.85,4)/(4,21.4)/(65.85,21.4). A handful of components (J_TOF, U4) also
needed small repositioning after the resize to clear new courtyard/pad collisions.

Component placement is net-correct and DRC-clean (0 shorting_items, 0 net_conflict, 0
courtyards_overlap, 0 clearance violations, 0 solder_mask_bridge, 0 invalid_outline as of
2026-07-03, post-compaction re-verification) but **no copper traces are routed yet** — only a
GND pour zone on In1.Cu (bounds updated to 44×46mm to match). This is intentional per this
project's established PCB workflow (`avionics/CLAUDE.md`: "PCBs are tightly packed. All final
component footprint positions will be done manually, after PCBs are populated and nets are
built by script.") — the script (`gen_jayne_pcb.py`) placed footprints and built nets;
subsequent manual compaction in the KiCad GUI is the "final positions done manually" step
this project's workflow anticipates. **Note:** `gen_jayne_pcb.py` itself still generates the
pre-compaction 78×80mm layout — it has not been updated to match the hand-compacted 1.0 × 2.75 in (25.4 × 69.85 mm)
result, so re-running it will not reproduce the current file (see "Generator Scripts" below).

**Open DRC finding, REFERRED TO USER 2026-07-12:** CI (`kicad-cli` 9.0.9, not available in the
assistant sandbox — the KiCad PPA host is blocked by this environment's egress policy) reports
U4 (TI ISOW1044BDFMR, SOIC-16W) with 1 `clearance` + 1 `solder_mask_bridge` hard DRC violation
(`actual 0.0000 mm` — copper touching). A same-day fix attempt that dropped each U4 pad's
explicit 90° local `at` rotation (reasoning: it looked redundant against the footprint's own
90° placement rotation, and the unplaced upstream `Package_SO:SOIC-16W_7.5x10.3mm_P1.27mm`
library footprint carries no per-pad rotation) was **reverted** after CI showed it made things
far worse — 32 hard violations, including genuine `shorting_items` between adjacent U4 pads
(GND/CANFD_TX, CANFD_TX/CANFD_STBY_N, CANFD_ISOGND/+5V, CANFD_ISO_L/CANFD_ISO_H, etc.). That
result shows the pad's stored `at` angle is *not* simply additive with the footprint's
placement rotation the way a naive rigid-body composition would suggest — the real semantics
kicad-cli applies here couldn't be confirmed without live DRC. **Do not re-attempt this fix
blind;** re-verify any candidate change against `kicad-cli pcb drc` (KiCad 9.0.x) before
committing. File is back at the pre-2026-07-12 state (1 clearance + 1 solder_mask_bridge on
U4, same as the rest of this section describes).

Mounting holes: 4× M3, symmetric 4 mm margin from each edge — (4,4), (65.85,4), (4,21.4), (65.85,21.4).

---

## Verified vs. Placeholder — Read Before Fabricating Anything

**Real, verified:**

- All net-level architecture/interconnect (which pin talks to which pin, UART crossing,
  CAN-FD, SPI buses, PGND/GND single-point isolation — verified via netlist export, only one
  bridge point between GND and PGND).
- TI ISOW1044BDFMR's SOIC-16W pinout (reused from Wash's own verified `gen_cape_a2.py`).
- AO3400 SOT-23 N-FET pinout.
- TPS65219 as the correct PMIC family for AM62A power (per TI's own SLVAFD0 app note),
  VQFN-32/RSM 5×5mm real body size.
- Microchip KSZ9477 as the correct part for HSR/PRP hardware redundancy (per AN3474) — NOT
  LAN9355/KSZ9563, which do not implement it. Real body size 14×14mm (128-TQFP-EP).
- AM62A7 real body size 18×18mm (484-ball FCBGA/FCCSP, AMB/ANF package).
- MSPM0G3507 real VSSOP-28 (DGS) package option, body ~7.1×4.9mm — smaller than the VQFN-48
  first assumed.
- SLB9670 real PG-VQFN-32 package, body ~5×5mm.
- Wurth 749010012A magnetics, Bourns SRF2012-100Y CMC, Nexperia PRTR5V0U2X TVS — all reused
  verbatim (pinout + footprint reference) from this project's own working Wash/TACCO generator.

**Placeholder / NOT real — shall be replaced before fabrication:**

- *(Resolved)* Placeholder ICs have been removed. U1 (AM62A) and U_PMIC are now integrated onto the real `phyCORE-AM62x_PCM071` SoM footprint. U2, U3, U4, and U5 now utilize verified, datasheet-accurate TQFP, QFN, and SOIC footprints.
- The JST-GH 5-pin Ethernet connector footprint is an untuned approximation of Wash's real
  `JST_GH_SM05B-GHS-TB_1x05-1MP_P1.25mm_Horizontal` part (pin count/pitch match; exact pad
  geometry not independently re-verified).
- Only 1 of 4 real MIPI CSI-2 data lanes is modeled on the camera interface.

---

## EMI Hardening Status: MATCHES PROJECT STANDARD (added 2026-07-03)

This project's EMI-hardening baseline (established on Wash/TACCO Rev R, TODO.md §1.2a) for any
board with external Ethernet or CAN-FD connectors is now matched:

| Bus | Wash/TACCO Rev R standard | Observer (this design) |
|---|---|---|
| Ethernet | LAN magnetics (isolation) + SRF2012-100Y CMC + PRTR5V0U2X TVS array, per port | **Wurth 749010012A magnetics + 2× SRF2012-100Y CMC + 2× PRTR5V0U2X TVS, per port** (both ring in and ring out) |
| CAN-FD | ISOW1044BDFMR — galvanically isolated transceiver, 5 kV reinforced insulation (IEC 62368-1 / VDE 0884-11) | **ISOW1044BDFMR** (same part) + SRF2012-100Y CMC + PRTR5V0U2X TVS |

Note: an earlier pass of this document cited "HX1188NL" as the Wash/TACCO magnetics part per a
stale TODO.md reference — the actual working `gen_cape_a2.py`/`add_eth_phy.py` generator
uses **Wurth 749010012A**, confirmed by reading that file directly; Observer now cites and reuses
that same real part, not the stale one.

All EMI-hardening parts/footprints (magnetics, CMC, TVS, isolated CAN transceiver) are REAL —
reused directly from this project's own verified `gen_cape_a2.py`/`gen_cape_a2_pcb.py`
symbols/pinouts, not fabricated placeholders. Two real bugs were caught and fixed while
wiring this in: (1) each Ethernet port had only modeled ONE differential pair instead of the
two (TX+/TX-/RX+/RX-) a real 10/100BASE-TX port needs; (2) the CMC/TVS glabels were initially
hand-wired at un-flipped local pin coordinates, landing on the wrong physical pin (the same
class of KiCad lib_symbol Y-up/Y-down bug caught earlier in this session) — fixed by routing
all of them through the same `glabel_pin`/`pwr_pin` helpers used everywhere else in the file.

**Still open:** the JST-GH 5-pin Ethernet connector footprint (`comp_jst_gh_5p`) is an
approximation of Wash's real `JST_GH_SM05B-GHS-TB_1x05-1MP_P1.25mm_Horizontal` footprint —
pad geometry was not independently re-verified against the real part this session, only the
pin count/pitch. Verify before fabrication.

---

## Mechanical Mounting and Wiring — Nose and Cargo Installs (added 2026-07-03)

Observer is a single 1.0 × 2.75 in (25.4 × 69.85 mm) double-sided board design installed at two physical locations.
Both installs share the same mounting-hole pattern — 4× M3, (4,4)/(65.85,4)/(4,21.4)/(65.85,21.4) mm
from the board's own corner — and the same connector set (J_PWR, J_ETH_IN, J_ETH_OUT,
J_CANFD, J_CAM1/J_CAM2, J_TOF, J_LASER). Only the local sensor harness and the board's
orientation/standoff depth differ per site.

**Per this project's own stated placement policy** (`airframe/CLAUDE.md` "Assembly and
Placement": *"Serenity's geometry is complex — bounding boxes and centroid calculations are
inadequate... if there is uncertainty about placement, request manual placement in FreeCAD"*),
the exact board pose below is a **proposed placement to verify in FreeCAD**, not a baked
position — no interior-pocket mesh exists yet at either site to check real clearance against.
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

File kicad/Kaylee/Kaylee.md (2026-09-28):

# FlightEngineer — Power Distribution Board Rev R

*Named after FlightEngineer Frye, ship's mechanic, Firefly-class vessel Serenity.*

**Author:** Steve Griffing, PE(CSE), CISSP-ISSEP, CPP
**License:** CC BY 4.0 — creativecommons.org/licenses/by/4.0
**Revision:** R (Rev R baseline; carried forward from Rev A, 2026-06-07; no design changes)
**Date:** 2026-06-11
**Status:** Schematic complete — PCB layout pending DRC sign-off

---

## Purpose

FlightEngineer replaces the generic off-the-shelf dual-BEC PDB-BEC module with a custom
four-layer PCB sized for the Serenity UAV power architecture. It provides:

- Coordinated multi-level fusing (main bus + per-ESC branch fuses)
- **Per-EDF independent power isolation**: each EDF output is electrically decoupled
  so that a stall or blown fuse on one EDF cannot collapse the supply to any other
  EDF, including the partner EDF in the same nacelle
- **Separated FC signal paths**: the forward EDF and aft EDF in each nacelle are
  commanded by different FC nodes — a single FC node failure cannot silence both
  EDFs in any nacelle
- Per-output current sensing via INA226 (reported over I2C to FC1 / Shepherd's room / Bay A)
- Per-cell battery monitoring via BQ76930 (6S balance lead input)
- Hardware-level battery protection FETs driven by BQ76930
- Dual redundant 5 V / 10 A SMPS (diode-OR'd) for avionics bus
- 6 V / 5 A SMPS for servo bus
- EMI suppression on main bus and all BEC outputs
- **Shield ground connection on every connector** (chassis ground pad or shielded
  JST-GH MP pin at each output)
- **All power cables twisted pair with per-output CM choke** and snap-on ferrites
  at both cable ends

Full electrical design rationale is documented in `docs/POWER_DISTRIBUTION.md`.

---

## Board Specification

| Parameter | Value |
|---|---|
| Board size | 90 × 65 mm |
| Layers | 4 (F.Cu signal, In1.Cu GND plane, In2.Cu VBAT power plane, B.Cu signal) |
| Copper weight | 4 oz (140 µm) on F.Cu / In2.Cu (main power); 1 oz (35 µm) on In1.Cu / B.Cu (signal / GND) |
| Min trace width | 0.20 mm (signal); ≥ 6 mm pour (ESC outputs) |
| Min clearance | 0.15 mm (signal); 3 mm between VBAT and GND pours |
| Surface finish | ENIG (gold) |
| Solder mask | Green |
| Max operating temp | 85 °C |
| PCB material | FR-4 TG170 |
| Fab notes | Order through JLCPCB or PCBWay; request 4-oz copper inner planes; no V-score |

---

## Connectors

All connectors carry a shield ground connection.  Power connectors use an M3
threaded brass insert adjacent to the connector body for cable braid/drain-wire
termination.  Signal connectors use a PGND via-pad within 3 mm of the connector
for shield drain wire attachment.  See Harness Specification for cable construction
requirements.
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

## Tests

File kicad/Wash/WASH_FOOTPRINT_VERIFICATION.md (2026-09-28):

# Wash (CAPE-A-2) — Footprint-vs-Datasheet Verification

**Author:** Claude (Opus 4.8), 2026-07-13
**License:** CC BY 4.0 — creativecommons.org/licenses/by/4.0
**Board:** `avionics/kicad/Wash/kicads/Wash.kicad_pcb`
**Method:** Every placed footprint's pad geometry (count, pitch, body, EP) was
extracted from the PCB and compared against the manufacturer datasheet in
`avionics/datasheets/`. Datasheets were text-extracted with `pdftotext`.

> *"It's just reputation" — so every land pattern here is checked against the
> silicon it must actually solder to, not a placeholder.*

---

## Summary verdict

**7 of 46 footprints are NOT manufacturable as drawn** (5 wrong land patterns +
2 placeholders). The board **cannot be fabricated** until these are rebuilt. A
further group is package-correct but needs a pinout/part-number confirmation.

| Verdict | Count | Refs |
| --- | ---: | --- |
| ❌ Wrong land pattern | 5 | CAN-TR, TPM, ETH1-PHY, ETH2-PHY, RS485, BARO |
| ❌ Placeholder (2-pad stub) | 2 | GPS, 1553-XFM |
| ❗ Land OK but net map broken | 2 | U-ISO-RX, U-ISO-TX (ISO6442) |
| ⚠ Land OK, needs part number | 3 | T-ETH/T-ETH2, X2Y-CAN/RS485, PWR-IN |
| ✅ Verified correct | rest | incl. all JST GH connectors — see tables |

Note: BARO plus the two ETH-PHYs make the "wrong" list 6 refs across 5 part types.

---

## ❌ Confirmed wrong land patterns

| Ref | Part | PCB footprint (WRONG) | Datasheet says | Source |
| --- | --- | --- | --- | --- |
| **CAN-TR** | ISOW1044BDFMR | `SOIC-16W_7.5x10.3mm` — **16 pads** | **20-pin DFM** (SOIC-20 land) — "DFM (20)", "20 PINS", Fig 7-1 | `isow1044.pdf` §7 |
| **TPM** | SLB9670 | `QFN-32-1EP_4x4mm_**P0.4mm**_EP2.65` | **VQFN-32, 0.5 mm pitch**, ~5×5 body, **EP 3.6×3.6** | `SLB_9670VQ20_Infineon.pdf` p.15 ("7 × 0.5 = 3.5"; "3.6 ±0.1") |
| **ETH1-PHY / ETH2-PHY** | ADIN1300BCPZ | `QFN-48-1EP_**7x7mm**` — **48 lead** | **40-lead LFCSP, 6×6 mm** (CP-40-26), 0.5 mm pitch, w/ EP | `adin1300.pdf` ("40-lead, 6 mm × 6 mm LFCSP") |
| **RS485** | ADM2795EBRWZ | `SOIC-**20W**_7.5x12.8mm` — **20 pads** | **16-lead SOIC_W (RW-16)** | `adm2795e.pdf` Table 3/4/7 ("16-Lead … RW-16") |
| **BARO** | BMP388 | `Bosch_LGA-**8**_2x**2.5**mm_P0.65` — **8 pads** | **10-pin metal-lid LGA, 2.0 × 2.0 mm** | `bst-bmp388-ds001.pdf` ("10-pin … 2.0 × 2.0 mm") |

Each of these is a hard fabrication defect: wrong pad count and/or wrong pitch
means the pads do not land on the part's leads. **Correcting them remaps
which net lands on which pin** — a flight-hardware footprint↔symbol change that
shall be done against the confirmed schematic pinout, not guessed (root
`CLAUDE.md`, avionics `CLAUDE.md`).

## ❌ Placeholder footprints (2-pad stubs, not real)

| Ref | Part | Footprint | Real package (datasheet) |
| --- | --- | --- | --- |
| **GPS** | SAM-M10Q-00B | `Package` — 1 dummy + 8×8 mm body blob | u-blox SAM-M10Q, LGA patch-antenna module (~15.5×15.5 mm, ~20+ LGA pads; `SAM-M10Q_DataSheet_UBX-22013293.pdf` §3.1) |
| **1553-XFM** | SM-1553-11 | `Package` — 1 dummy + 4.8×3.36 mm body blob | Beta/SM1553-series data-bus pulse transformer — **thru-hole**, multi-pin (`SM1553-Series...RevD.pdf`) |

Both need real footprints authored from the datasheet pinouts before layout.
Note the SM1553 series is **through-hole**, which changes the PCB (THT pads +
drills) versus the current SMD stub.

---

## ❗ ISO isolators — land pattern OK, but net mapping is non-functional

**U-ISO-RX / U-ISO-TX (ISO7642FDWRR → ISO6442, per TI EOL/replacement guidance):**

- **Land pattern `SOIC-16W` is CORRECT** for the Wide-SOIC **DW-16** package
  (`iso6442.pdf` — "Wide-SOIC (DW-16)"). ✅
- **The ISO7642 → ISO6442 substitution is a valid drop-in:** both are 4-channel,
  **2-forward / 2-reverse**, DW-16, pin-compatible. ✅ (BOM string / `Wash.md` /
  `REFERENCES.md` should be updated ISO7642FDWRR → ISO6442; fold into the rework below.)
- **BUT the placed net→pin assignment does not work** (checked against ISO6442
  Table 5-1). Two hard errors:
  1. **Power/ground pins carry signal nets** — e.g. pin 2 (`GND1`) = `RMII0_RXD0`,
     pin 15 (`GND2`) = `RMII0_RXD0`, pin 2 of U-ISO-TX (`GND1`) = `RMII0_REF_CLK`.
     The device cannot power up or function like this.
  2. **Every channel is shorted across the isolation barrier** — the *same* net
     sits on the side-1 input pin and the side-2 output pin of each channel
     (RMII0_RXD1 on pins 3 & 14, CRS_DV on 4 & 13, etc.). That defeats the
     galvanic isolation entirely; there are no separate primary/secondary nets.
  3. **Architecture concern:** RMII `REF_CLK` is 50 MHz and is routed through a
     general-purpose digital isolator; continuous-clock isolation at that rate is
     marginal-to-unworkable and adds skew that breaks RMII timing. The whole
     "isolate RMII with two 4-channel digital isolators" scheme needs design review.

  This is a **schematic/net-correctness defect, not a land-pattern defect** — but
  it means the ETH-isolation subcircuit as drawn is non-functional and shall be
  re-architected + re-netted, not merely routed. Depends on a clean ERC (§1.2a).

## ❗ Net→pin maps are wrong on multiple parts (schematic-rooted, not geometry)

Verifying pinouts surfaced that the **net-to-pin assignments are wrong**, independent
of the land-pattern errors. Confirmed on two parts so far:

- **TPM (SLB9670)** vs. datasheet Fig 1 (PG-VQFN-32-13): TPM_RSTN on pin 1 (=NCI/VDD;
  RST# is pin 17), SPI0_MISO on pin 22 (=VDD; MISO is 24), SPI0_CLK on pin 23 (=GND;
  SCLK is 19), TPM_IRQN on pin 24 (=MISO; PIRQ# is 18), SPI0_CS_TPM on pin 28 (=NC;
  CS# is 20). Only SPI0_MOSI (pin 21) is right. Correct map: 17→TPM_RSTN, 18→TPM_IRQN,
  19→SPI0_CLK, 20→SPI0_CS_TPM, 21→SPI0_MOSI, 22→+3V3, 23→GND, 24→SPI0_MISO, EP→GND.
- **U-ISO-RX / U-ISO-TX (ISO6442)** — signals on power/ground pins, every channel
  shorted across the barrier (documented above).

These are **schematic/netlist errors**, not land-pattern errors: the wrong pin→net
associations originate in the symbols that drive the netlist. **Fixing only the PCB
footprints would fight the schematic on the next sync and re-create the exact
sch↔pcb divergence documented for Emma/TACCO.** The rebuild shall therefore be
**schematic-first** (author correct symbols/pinouts → correct footprints follow →
re-sync PCB), or explicitly accept a PCB-first patch with the schematic to catch up.

## ⚠ Package correct, but needs a part number

| Ref(s) | Part | Note |
| --- | --- | --- |
| T-ETH, T-ETH2 | Würth 749010012A | Custom 8-pad `ETH_XFMR_8P_5x3.5mm`. Part confirmed (WE-LAN 10/100 SMT). Verify the 8-pad pinout/pin-1 orientation against `749010012A.pdf`. |
| X2Y-CAN, X2Y-RS485 | 4.7 nF X2Y | Custom `X2Y_Cap_4T_0402`. **No manufacturer part number / datasheet supplied** — cannot verify the 4-terminal land. Need the actual X2Y device (e.g. Johanson) part number. |
| PWR-IN | Molex Nano-Fit 4P | Pitch consistent (2.5 mm), but no Nano-Fit datasheet supplied to confirm pad/keying. |

## ✅ Connectors verified correct against `eGH.pdf`

JST **GH** series confirmed: 1.25 mm pitch, SM03B/SM04B/SM05B/SM06B-GHS-TB all
listed in `eGH.pdf`. The custom `JST_GH_4P` / `JST_GH_3P` lands (1.25 mm pitch)
and the standard `JST_GH_SM05B-GHS-TB…Horizontal` (ESC-PWM) all match — CAN-FD,
RS-485, ETH1, ETH2, MIL-1553, ESC-TLM, GPIO-A…F connectors verified. (The earlier
`SM04B-SRSS-TB.pdf` was the wrong series and is superseded by `eGH.pdf`.)

---

## ✅ Verified correct against datasheet

| Ref(s) | Part | Footprint | Datasheet confirms |
| --- | --- | --- | --- |
| 1553-DRV | DS26LV31 | `SOIC-16_3.9x9.9mm` | `ds26lv31qml.pdf` — SOIC (D), 16 |
| 1553-RCV | DS26LV32 | `SOIC-16_3.9x9.9mm` | `ds26lv32at.pdf` — "SOIC (D) 16" |
| IMU | ICM-42688-P | `LGA-14_3x2.5mm_P0.5mm` | `ds-000347...pdf` — "2.5×3.0×0.91 mm 14-pin LGA" |
| U-GPIO | PCA9555DB | `SSOP-24_5.3x8.2mm_P0.65mm` | `PCA9555.pdf` — SSOP24 (DB) |
| TVS-1553 | SMAJ33CA | `DO-214AC_SMA` | standard SMA — matches |
| TVS-CAN, TVS-RS485 | PRTR5V0U2X | `SOT-363_SC-88` | standard 6-pin SOT-363 — matches |
| CMC-CAN, CMC-RS485 | SRF2012-100Y | `Bourns_SRF2012_4T` | `SRF2012A.pdf` — 2012 4-terminal CMC |
| FB1 | 742792512 | `C_0805_2012Metric` | 0805 2-terminal ferrite — acceptable |
| C-GPIO | 100 nF | `C_0805_2012Metric` | standard 0805 |
| SERVO-PWM | 1×8 header | `Connector_PinHeader_2.54mm` | standard 2.54 mm header |
| PB2-P1, PB2-P2 | PB2-I P1/P2 | `2x18_*_Socket` | 2.54 mm 2×18 — matches PocketBeagle 2 header |

---

## ❗❗ Schematic and PCB are two different designs (root cause)

Confirmed 2026-07-13 by inspecting `Wash.kicad_sch` lib_symbols/instances:

- **The schematic is a DP83825I design; the PCB is an ADIN1300 design.** The
  schematic instantiates `DP83825I` ×2 + `HX1188NL` ×2 + `TPS62933` ×2 (matching
  `Wash.md`). The PCB instead has `ADIN1300` ×2 + `749010012A` + ISO isolators and
  **no** DP83825I/HX1188NL/TPS62933. The Ethernet front-end was reworked on the PCB
  and never captured in the schematic. So the ADIN1300 "wrong footprint" finding is
  only meaningful if ADIN1300 is the intended architecture.
- **The schematic symbols are partial/wrong-pinout, not datasheet-accurate:**
  ISOW1044BDFMR symbol = **9 pins** (real = 20), ADM2795EBRWZ = **10** (real = 16),
  SLB9670 = **8** (real = 32), SAM-M10Q = **7** (real = 16+), BMP388 = **7** (real =
  10). They draw only the pins the designer chose to wire, and (per the TPM/ISO
  checks above) some of those are on the wrong physical pins.
- The schematic also carries parts not stuffed on the PCB (MMC5983MA + QMC5883L
  compasses, INA219/INA226 monitors) — further evidence the two files are different
  board revisions.

**Neither file is currently a clean source of truth.** A proper schematic-first
rebuild shall (1) pick the Ethernet architecture (DP83825I vs ADIN1300), (2) author
datasheet-accurate full-pinout symbols for each IC, (3) wire them correctly,
(4) associate correct footprints, (5) regenerate/re-sync the PCB, (6) ERC/DRC clean.

## Cross-cutting: documentation vs. as-built architecture

The supplied datasheets (ADIN1300, ADM2795E, ISO-series, Würth 749010012A)
confirm the **PCB's** Ethernet front-end is authoritative and **`Wash.md` §1 is
stale**. `Wash.md` still documents a DP83825I + HX1188NL + TPS62933 design that
is not on the board. `Wash.md` §§1–3 need to be rewritten to the as-built
ADIN1300 + 749010012A + ISO6442 + ADM2795E (RW-16) design, and the §3 claim that
the ADM2795E is "SOIC-20W" with an "internal DC/DC" shall be reconciled with the
16-lead RW-16 datasheet.

## Recommended fix order

1. Resolve the ⚠ part-number/datasheet gaps (ISO7642 vs ISO6442; X2Y P/N; JST
   GH drawing; Molex Nano-Fit) so every land pattern maps to a confirmed part.
2. Confirm the schematic pinout for each ❌ part (the schematic ERC is not clean;
   see §1.2a), then rebuild the 5 wrong land patterns with correct pin→net mapping.
3. Author real footprints for GPS (SAM-M10Q LGA) and 1553-XFM (SM1553 THT).
4. Re-run `kicad-cli pcb drc --schematic-parity` and proceed to routing.

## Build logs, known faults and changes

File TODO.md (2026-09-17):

# Serenity UAV — Avionics Work Breakdown Structure

**Author:** Steve Griffing, PE(CSE), CISSP-ISSEP, CPP
**License:** CC BY 4.0 — creativecommons.org/licenses/by/4.0
**Current design revision:** Rev S (2026-07-04)
**This file generated by:** Claude (Opus 4.8), 2026-07-05, from the master WBS
snapshot (`TODO.md`, md5 `829246af291844cd6b557230e8430a12`).

> **Subordinate to the master WBS.** The repository-root [`TODO.md`](../TODO.md)
> remains the single authoritative Work Breakdown Structure. This document is the
> **Avionics-scoped view**: it carries only the WBS branches owned by this subsystem,
> with master §-numbering preserved for traceability. When an item closes, close it
> in the master first, then reflect it here (see the standing rule in the root
> `CLAUDE.md`). **&#9733; = the branch is on the critical path to first flight
> (Phase 5).** Open-item counts are as of the snapshot; sub-items are indented as in
> the master. Procurement bills of material (master §2.x) are BOM tables, not
> checkbox tasks — they are referenced, not duplicated.

*"I'm a leaf on the wind — watch how I soar. — Wash"*

---

## Owned WBS branches — open-item summary

| Master § | Branch | Open | First flight |
|---|---|-----:|:---:|
| §1.2a | 1.2a — PCB Design: Wash, Zoe, Emma (EMI-hardened) | 37 | &#9733; |
| §1.2b | 1.2b — PCB Redesigns: Emma / Zoe / FlightEngineer Rev S1 | 26 | &#9733; |
| §1.2c | 1.2c — PCB Design: Observer (Observer vision/ToF/laser subsystem) | 22 | — |
| §1.4 | 1.4 — EMI Hardening Beyond the PCBs (500 W/m^2) | 43 | &#9733; |
| §0.6 | 0.6 — IEC 62368-1 PCB Layout Isolation Verification | 0 | &#9733; |
| §1.3 | 1.3 — PCB Design: XCVR-49MHZ-1 (SUPERSEDED) | 0 | — |
| §1.2 | 1.2 — PCB Design: Cape-A-1 and Cape-B-1 (archived) | 0 | — |
| §4.1 | 4.1 — Firmware: Completed / carry-forward | 0 | — |
| §4.2 | 4.2 — FC Node (Wash) Firmware | 38 | &#9733; |
| §4.3 | 4.3 — CN Node (Zoe) Firmware | 36 | &#9733; |
| §4.4 | 4.4 — Both Nodes (shared firmware) | 22 | &#9733; |
| §4.6 | 4.6 — Observer Node Firmware (Observer vision subsystem) | 15 | — |
| §1.8 | 1.8 — Names | 0 | — |
| §1.9 | 1.9 — Avionics Workload Balancing | 0 | — |
| | **Total open (this subsystem)** | **239** | |

---

## Cross-cutting system: Observer (cargo handling)

> **Observer is a ship-level integrating system, not a single WBS branch.** It comprises the cargo-bay doors, the N20 winch / Dyneema hoist, the auto-latch, the gondola, **and the Observer vision/ToF/laser PCB as its sensing subsystem**. Its work is distributed across subsystem WBS files:
>
> | Observer subsystem | Where tracked |
> |---|---|
> | Doors, winch, latch, gondola — geometry/STLs | [airframe/TODO.md](../airframe/TODO.md) §1.1 |
> | Cargo procurement (BOM) | master [`TODO.md` §2.6](../TODO.md) |
> | **Observer** vision/ToF/laser board | [avionics/TODO.md](../avionics/TODO.md) §1.2c |
> | **Observer** node firmware | [avionics/TODO.md](../avionics/TODO.md) §4.6 |
> | Payload/winch control firmware (Simon = payload-primary) | [avionics/TODO.md](../avionics/TODO.md) §4.2 / §4.3 |
> | Physical assembly & install | [graphical-build-guide/TODO.md](../graphical-build-guide/TODO.md) Phase 7 |
> | Range-extender battery in the cargo bay (deferred) | [deferred/TODO.md](../deferred/TODO.md) Phase 12 |
>
> **Note for this file:** §1.2c (Observer board) and §4.6 (Observer firmware) below are the sensing subsystem of Observer; FlightEngineer's dedicated Observer 5 V rail lives in §1.2b. The mechanical cargo hardware they serve is in [airframe/TODO.md](../airframe/TODO.md) and Phase 7.

## §1.2a — PCB Design: Wash, Zoe, Emma (EMI-hardened) &#9733;

*Master:* [`TODO.md` §1.2a](../TODO.md) — 37 open, 7 done at snapshot.

    - [ ] Verify/add I2C1 pull-ups (≈4.7 kΩ to +3V3 on SDA/SCL) — none on cape;
        confirm whether the PB2-I provides them.
    - [ ] Finalise placement of U-GPIO/C-GPIO (added at a tentative location).
    - [ ] Finalise ESC-PWM placement (added at a tentative location).
- [ ] **Reconcile Wash.md §14 field-connector table with the actual PCB
    connectors** (PCB has SERVO-PWM 1×8 + GPIO-A…F + ESC-TLM; §14 lists J_SERVO/
    J_ESC/J_GPS/J_ENC/J_SBUS/J_VBAT/J_FAN). Bring the doc and board into agreement.
- [ ] **Wire the MIL-1553 connector + transformer.** `MIL-1553` connector and the
    `1553-XFM` transformer coupling to the bus are unwired at the IC level; the
    driver/receiver (DS26LV31/32) are only partially netted.
- [ ] **Redesign the tamper mesh as a per-domain anti-tamper mesh (all 4 capes).**
    The current `TMESH_P`/`TMESH_N` cross-hatch grid on F.Cu/B.Cu shorts across SMD
    pads and across the isolated `GND2_*` domains (≈335 of Wash's 465 DRC errors;
    similar on TACCO). Rework as one monitored mesh net per isolation region
    (secure/`GND` + per-`GND2_CAN`/`GND2_ETH`/`GND2_RS485` field side), keeping the
    0.5 mm `ISOLATION` creepage moat clear between domains. **BLOCKS DRC-clean.**
    Quantified against the IEC 62368-1 reinforced-insulation requirement in §0.6
    (2026-06-22): 13 genuine cross-domain `TMESH`-vs-`GND2_*` violations on Wash
    (min 0.125 mm), 9 on TACCO (min 0.0 mm/direct contact) — both far short of the
    0.5 mm netclass minimum and the ≥ 8 mm physical creepage target in `Wash.md`.
- [ ] **Carry the tamper signal over the link for the TPM-less boards.** FlightEngineer
    and Emma have no local TPM: route FlightEngineer's mesh signal to Wash and
    Emma's to TACCO over the inter-board link.
- [ ] **Route the rearranged capes.** The manual component reseat left ~60 signal
    nets per cape unrouted (7 power/ground nets are planes). Headless freerouting
    was **not** usable (see toolchain findings in `avionics/kicad/README.md`):
    KiCad 9.0.2 `ExportSpecctraDSN` is broken in standalone Python, and freerouting
    2.1 headless never self-exits and emits incomplete SES. **Finish routing in the
    KiCad GUI**; route the impedance-controlled Ethernet pairs interactively
    (length-matched, 100 Ω ±10% MDI). **BLOCKS gerbers / fab.**
- [ ] **Clear residual DRC after mesh + routing** (counts measured 2026-06-12,
    error+warning): Wash 465 / 121 unconnected, TACCO 554 / 146, Emma 421 /
    160, FlightEngineer 221 / 181. Remaining types after the mesh fix are mostly
    silk-over-copper, text-height, courtyard-overlap, and lib-footprint mismatch.
- [ ] **Wash footprint-vs-datasheet verification — DONE 2026-07-13 (Claude Opus 4.8);
    7 footprints are NOT manufacturable, must be rebuilt before fab.** Full report:
    `avionics/kicad/Wash/WASH_FOOTPRINT_VERIFICATION.md`. Fixing any of these remaps
    pin→net on flight hardware, so each needs the confirmed schematic pinout first (ERC
    is not clean — see below) and MUST NOT be guessed.
    - [ ] **CAN-TR (ISOW1044BDFMR): wrong land — has 16-pad `SOIC-16W`, part is a
        20-pin DFM (SOIC-20 land).** Datasheet `isow1044.pdf` §7 / Fig 7-1. (This is the
        fleet-wide ISOW1044 footprint error; confirmed present on Wash.)
    - [ ] **TPM (SLB9670): wrong land — has `QFN-32 4×4 P0.4mm EP2.65`, part is VQFN-32
        0.5 mm pitch, ~5×5 body, EP 3.6×3.6.** Datasheet `SLB_9670VQ20_Infineon.pdf` p.15.
    - [ ] **ETH1-PHY / ETH2-PHY (ADIN1300BCPZ): wrong land — has `QFN-48 7×7`, part is
        40-lead LFCSP 6×6 mm (CP-40-26) w/ EP.** Datasheet `adin1300.pdf`.
    - [ ] **RS485 (ADM2795EBRWZ): wrong land — has 20-pad `SOIC-20W`, part is 16-lead
        SOIC_W (RW-16).** Datasheet `adm2795e.pdf` Tables 3/4/7. (Also fix `Wash.md` §3.)
    - [ ] **BARO (BMP388): wrong land — has 8-pad `LGA-8 2.0×2.5`, part is 10-pin metal-lid
        LGA 2.0×2.0 mm.** Datasheet `bst-bmp388-ds001.pdf`.
    - [ ] **GPS (SAM-M10Q-00B): placeholder `Package` (2-pad blob) — author real u-blox
        SAM-M10Q LGA module footprint.** Datasheet `SAM-M10Q_DataSheet_UBX-22013293.pdf` §3.1.
    - [ ] **1553-XFM (SM-1553-11): placeholder `Package` (2-pad blob) — author real SM1553
        transformer footprint. NOTE: SM1553 series is THROUGH-HOLE** (adds THT pads/drills
        vs current SMD stub). Datasheet `SM1553-Series...RevD.pdf`.
    - [ ] **U-ISO-RX / U-ISO-TX net mapping is non-functional (ISO6442) — land pattern is
        FINE, the wiring is not.** Part resolved 2026-07-13: ISO7642FDWRR is EOL, TI
        replacement is **ISO6442** (drop-in: DW-16 / SOIC-16W, 2-forward/2-reverse,
        pin-compatible — `iso6442.pdf`), so the `SOIC-16W` land is correct. BUT checked
        against ISO6442 Table 5-1: (a) power/gnd pins carry signals (pin 2 `GND1`=RMII0_RXD0;
        U-ISO-TX pin 2 `GND1`=RMII0_REF_CLK) — won't power up; (b) every channel is shorted
        across the barrier (same net on side-1 input AND side-2 output pin) — no isolation;
        (c) 50 MHz RMII `REF_CLK` through a general-purpose digital isolator is unworkable.
        The ETH-isolation subcircuit must be re-architected + re-netted (schematic-first),
        and the BOM/`Wash.md`/`REFERENCES.md` strings changed ISO7642FDWRR → ISO6442.
    - [ ] **Remaining part-number gaps (land OK, part unconfirmed):** (a) X2Y 4.7 nF caps
        (`X2Y_Cap_4T_0402`) — no mfr P/N supplied; (b) Molex Nano-Fit 4P (PWR-IN) — no
        datasheet supplied. *(JST GH 4P/3P connectors VERIFIED CORRECT vs `eGH.pdf` — GH
        1.25 mm pitch, SM0xB-GHS-TB — no action.)*
    - [ ] **Rewrite `Wash.md` §§1–3 to the as-built architecture** — board uses ADIN1300 +
        Würth 749010012A + ISO7642 + ADM2795E(RW-16); `Wash.md` still documents a stale
        DP83825I + HX1188NL + TPS62933 design that is not on the PCB.
    - [ ] **Verified CORRECT (no action):** DS26LV31, DS26LV32, ICM-42688-P, PCA9555DB,
        SMAJ33CA, PRTR5V0U2X, SRF2012-100Y, 742792512, PB2 P1/P2 sockets, SERVO-PWM header.
- [ ] **Wash SCHEMATIC-FIRST REBUILD — decided + started 2026-07-14 (user).**
    Verification proved the schematic (`Wash.kicad_sch`) and PCB are *different designs*
    (schematic = DP83825I + HX1188NL + TPS62933; PCB = ADIN1300 + 749010012A + ISO6442),
    and that net→pin maps are wrong on multiple parts (TPM signals on NC/VDD/GND pins;
    ISO6442 channels shorted). Fixing the PCB alone would re-create the Emma/TACCO sch↔pcb
    divergence, so the rebuild is **schematic-first** (user choice). **Ethernet PHY =
    ADIN1300** (the EMI-hardening rework moved to ADI's industrial PHY; it's on the PCB and
    is the datasheet on hand) — `Wash.md`/schematic DP83825I baseline is superseded.
    Auditable generator: `avionics/kicad/Wash/scripts/gen_wash_sch.py`, datasheet-accurate
    full-pinout symbols → `kicads/Wash_rebuild.kicad_sch` (loads in kicad-cli 9.0.2; ERC
    only expected off-sheet-global warnings).
    - [x] Core isolated-bus + security + GPS ICs authored with full datasheet pinouts:
        **CAN-TR (ISOW1044, 20-pin), RS485 (ADM2795E, 16-pin RW-16), TPM (SLB9670, 32-pin
        correct 17–24 SPI map), GPS (SAM-M10Q, 16-pin).**
    - [ ] Author ETH section on **ADIN1300** (40-LFCSP) + Würth 749010012A magnetics +
        ISO6442 — redesign the RMII isolation (current scheme shorts the barrier / 50 MHz
        REF_CLK through a digital isolator is unworkable).
    - [ ] Add remaining ICs: 1553 (DS26LV31/32 + SM1553 xfmr), IMU (ICM-42688-P), baro
        (BMP388, 10-pin), compass (MMC5983MA/QMC5883L), INA226, PCA9555, 74LVC1G14.
    - [ ] Add PB2-P1/P2 (2×36) SoC headers + connectors + passives (TVS/CMC/X2Y-Syfer-0805/
        Nano-Fit); tie the off-sheet global labels; drive GND/power (PWR_FLAG) to clear ERC.
    - [ ] Associate corrected footprints (per WASH_FOOTPRINT_VERIFICATION.md) to each symbol;
        regenerate/re-sync the PCB; ERC + DRC --schematic-parity to zero.
    - [ ] Once approved, promote `Wash_rebuild.kicad_sch` → `Wash.kicad_sch` (archive old).
- [ ] **Finish Wash PCB (CAPE-A-2) close-out pass:**
    - [ ] Verify every external-facing connector (SERVO-PWM, ESC-PWM, MIL-1553, CAN-FD,
        RS-485, ETH) is a shielded-shell part with shell tied to PGND — audit against
        the footprint Description pinout already documented at §1.2 line ~1340.
    - [ ] Run ERC/DRC net-validity pass — confirm zero unconnected nets outside the
        13-net Emma-style residual list; cross-check against the 465/121 DRC count
        already logged for Wash at §1.2.
    - [ ] Verify all ferrite beads are placed at each digital/RF section boundary and
        on +5V/+3V3 entering from off-board connectors (pattern already used on
        Emma's +5V boundary, §1.2/§1.3 Phase 3).
    - [ ] Verify isolation caps/creepage moat (0.5 mm `ISOLATION`) are intact after the
        per-domain tamper-mesh rework (§1.2, "Redesign the tamper mesh").
- [ ] **Add SBUS/UART DIP switch to Wash** — add a 2-position DIP (or solder-jumper
    pair) to select SBUS vs. plain UART framing on the existing J_SBUS-equivalent
    pad, matching the J_SBUS line item already in Wash.md §14's field-connector
    table (§1.2, "Reconcile Wash.md §14...").
- [ ] **Generate Wash gerbers** — `CAPE-A-2.kicad_pcb` complete; run DRC to zero errors in
    KiCad; export to `avionics/kicad/gerbers/CAPE-A-2/`; re-export drill files.
    - **BLOCKS Wash fab order**
- [ ] **Generate TACCO gerbers** — `CAPE-B-2.kicad_pcb` complete; same DRC + export procedure;
    export to `avionics/kicad/gerbers/CAPE-B-2/`.
    - **BLOCKS TACCO fab order**
- [ ] **Zigbee RF chain was never actually added to TACCO — PCB scope gap (flagged 2026-06-22,
    cross-ref §1.4.2).** The "remove Wi-Fi, sik, and loRa antennas" item above (2026-06-05)
    names Zigbee as a target XCVR circuit, but only LoRa/SiK/Wi-Fi filter chains were built;
    `TACCO.kicad_sch` has no CC2652R7 (or equivalent Zigbee SoC), no Zigbee antenna filter, and
    no SMA/diplexer pad. `CLAUDE.md` lists Zigbee 2.4 GHz as one of the 4 required external
    C2 links — this is a real hardware gap, not yet scheduled to a revision. **Antenna
    strategy already decided (§1.4.2, 2026-06-22):** restrict WL1837MOD Wi-Fi to 5 GHz only
    and feed CC2652R7's 2.4 GHz path through a passive 2.4/5 GHz diplexer onto the existing
    shared Wi-Fi antenna (no separate Zigbee antenna/SMA pad needed). Still open: add
    CC2652R7 + diplexer to a Cape-B-2 schematic revision; decide which bay(s) carry it.
- [ ] **Generate Emma gerbers** — `XCVR-49MHZ-2.kicad_pcb` complete; export to
    `avionics/kicad/gerbers/XCVR-49MHZ-2/`.
    - **BLOCKS Emma fab order**
- [ ] **FCC Part 15 §15.235 pre-compliance checklist for Emma** — document field strength
    (≤10,000 µV/m at 3 m per §15.235(a), ≈30 µW / −15.2 dBm EIRP-equivalent — requires firmware
    PA limit, not the ≤100 mW previously assumed), harmonic suppression ≥40 dBc at 2nd/3rd
    harmonics (§15.235(b)/§15.209), FCC ID silkscreen labeling block (§2.803/§15.19).  Not
    Part 95 — see §0.1.
- [ ] **EMI isolation validation checklist** — verify isolation barrier clearance: ISOW1044BDFMR
    5 kV working voltage; ADM2795EBRWZ 5 kV working voltage; measure CMRR at 1 MHz on CAN and
    RS-485 channels; verify differential impedance 100 Ω ±10% on ETH MDI traces.
- [ ] **Merge `claude/cape-em-harsh-variants-9Yfr1` → master** after gerbers pass DRC and
    pre-compliance checklist is signed off.
- [ ] **Design Faraday cages / boxes to protect all PCBs** — minimize weight/space while meeting
    the 500 W/m² design objective. Placeholder geometry (FAR-CAGE-AV 76×56×88 mm, FAR-GASKET-AV,
    FAR-FAN-40, FAR-EMI-VENT-40, FAR-BOND-STRAP, FAR-FT-PANEL, FAR-FERRITE-4MM) already exists at
    §1.1.5 (364 g / 0.80 lbm system total) — these sub-tasks convert the placeholders into
    real, build-ready enclosures:
    - [ ] **Shepherd's Room cage** (Cape-A-2 + Cape-B-2 stack, no Emma) — final wall thickness,
        seam/gasket detail, FAR-FAN-40 mount, FAR-EMI-VENT-40 vent location.
    - [ ] **Inara's Shuttle cage** (Cape-A-2 + Cape-B-2 stack, no Emma) — same scope as Shepherd's.
    - [ ] **River's Room cage** (Cape-A-2 + Cape-B-2 + Emma stack) — add Emma board clearance and
        LoRa/49 MHz feedthrough ports to the FAR-FT-PANEL design.
    - [ ] **Simon's Medbay cage** (Cape-A-2 + Cape-B-2 + Emma stack) — same scope as River's Room.
    - [ ] **FlightEngineer (PDB) enclosure** — verify whether the PDB needs a full Faraday cage or only a
        bond strap to the keel ground plane (no TPM/RF on FlightEngineer; see §1.2 "Carry the tamper
        signal over the link for the TPM-less boards").
    - [ ] Bond each cage to the airframe ground reference via FAR-BOND-STRAP with no second
        return path (avoid ground loops per §1.4.1 prose constraint).
    - [ ] Re-run the §1.1.5 mass budget after all 5 enclosures are finalized — confirm cumulative
        T/W stays ≥1.2 (currently estimated ~1.19–1.25, §1.1.5).
- [ ] **Specify / implement tightly twisted pair bonded shielded wiring throughout the aircraft** —
    per-bus-type wiring spec (duplicates the per-bus breakdown tracked at §1.4.3/§1.4.4; this
    item is the airframe-wide harness/cable-selection pass, those are the connector/pinout pass):
    - [ ] CAN FD trunk (inter-node ring) — shielded twisted pair, 120 Ω characteristic impedance,
        drain wire bonded at each node chassis, not floating mid-run.
    - [ ] RS-485 trunk — shielded twisted pair, 120 Ω, daisy-chain topology, end termination at
        the two physical bus ends only.
    - [ ] MIL-STD-1553B bus — twinax/twisted-shielded-pair per the existing 1553-XFM transformer
        coupling spec (§1.2), stub length ≤1 ft from coupler to RT.
    - [ ] Ethernet (CPSW3G ring) — shielded Cat5e/Cat6, 100 Ω ±10% MDI pairs matching the
        impedance-controlled PCB traces already specified at §1.2.
    - [ ] Servo/PWM and ESC telemetry leads — twisted pair, routed ≥5 mm from RF/antenna runs.
    - [ ] Power harness (14 AWG nacelle feeds, battery-to-FlightEngineer) — twisted where co-routed with
        signal wiring; ferrite bead at each digital/RF section boundary crossing.

## §1.2b — PCB Redesigns: Emma / Zoe / FlightEngineer Rev S1 &#9733;

*Master:* [`TODO.md` §1.2b](../TODO.md) — 26 open, 18 done at snapshot.

- [ ] **Emma Rev S1 — add LoRa, replace JST with P1+P2 socket rails**
    - Add RFM95W 915 MHz LoRa module (SPI interface to PB2-I via P1 header pins).
    - Replace JST GH 6P connector with 2× 20-pin 2.54 mm socket rails (P1 + P2),
        matching TACCO passthrough rail pinout so Emma stacks cleanly on top.
    - Update SRF2012-100Y CMC + TVS guard to cover LoRa SPI and antenna lines.
    - Update silk/fab layer: "Emma Rev S1 — 49 MHz AX.25 + LoRa 915 MHz".
    - Fitted in: River's Room, Simon's Medbay only (2 boards total).
    - Run DRC → zero errors; generate gerbers to `avionics/kicad/gerbers/Emma-S1/`.
    - **BLOCKS Emma fabrication order.**
    - [ ] **Schematic-first reconciliation — DECISIONS LOCKED 2026-07-04 (user).**
        Resolves the PCB-ahead-of-schematic gap by authoring `Emma.kicad_sch` to be the
        source of truth, matching the as-placed PCB except for the topology changes below.
        Migration is driven by an auditable generator (`gen_emma_sch.py`, repository script
        convention) and gated on `kicad-cli sch erc` / `pcb drc`.
        - **DROP J1 (JST-GH-6P "CAPE-B IF").** The modem host UART moves onto the PB2
            passthrough rails: modem TX → `UART_RCRS_RX` (PB2-P1 pin 15), modem RX →
            `UART_RCRS_TX` (PB2-P1 pin 16). This honors the root-`CLAUDE.md` "replace JST
            GH 6P with P1+P2 socket rails" intent (chosen over the lower-rework "keep J1"
            option). Was: J1 kept live alongside the rails.
        - **PTT_N → repurposed PB2-P2 payload GPIO,** presence-gated by a cape-detect
            device-tree overlay (cape-ID EEPROM / GPIO strap → DT overlay muxes the pad to
            GPIO only when Emma is detected; otherwise it keeps its `SERVO*`/payload
            function). Emma has no on-board MCU, so the host must key the T/R switch; the
            fixed PB2 pinout has no spare GPIO, hence the repurpose. **Firmware/pinmux
            sign-off still required**, and note **Simon is payload-primary** (drives Observer
            cargo/WINCH/LOAD_CELL) so his payload pads contend — River (flight-primary) has
            slack. Provisional pad: PB2-P2 pin 1 (`SERVO7` ball).
        - **RSSI → 1-bit `RSSI_DCD`.** Analog `RSSI_ANA` cannot ride the rail (AM62x GPADC
            inputs are dedicated analog balls, not muxable onto a digital header pad). Add an
            on-board comparator (`RSSI_CMP`, LMV331-class) thresholding `RSSI_ANA`; its digital
            output `RSSI_DCD` rides a second presence-gated payload GPIO (provisional PB2-P2
            pin 2, `SERVO6` ball). Analog `RSSI_ANA` retained as a board test point.
        - [ ] **RSSI_DCD still to route (1 net).** RSSI_CMP.5 → PB2-P2 pad 2 (105.4,130.2) is a
            ~28 mm cross-board run through the ETH-PHY/LoRa (B.Cu) and the PB2 header (bottom
            edge) congestion; a naive route shorts/mask-bridges heavily. Route interactively
            (GUI push-shove) or with a real autorouter — `route_emma_rssi.py dcd` holds a
            starting attempt. This is the RSSI carrier-detect **output** to the host, so the
            feature is incomplete until it lands.
        - [ ] **`RSSI_CMP` part/pinout PROVISIONAL — pending datasheet vetting.** Value is a
            placeholder "LMV331-class"; pad→net is by FUNCTION and matches the schematic
            symbol, but the real comparator's part number + SOT-23-5 pin order MUST be
            confirmed and a `REFERENCES.md` entry added before layout is final (same
            discipline as the Class 3B laser, §1.2c). Also confirm push-pull vs open-drain
            (a pull-up on `RSSI_DCD` is needed if open-drain).
        - [ ] **PTT_N / RSSI_DCD presence-gated pinmux — firmware sign-off owed.** PB2-P2
            pin 1 (SERVO7 ball) / pin 2 (SERVO6 ball) are repurposed only when an Emma
            cape-ID is detected (DT overlay). **Simon is payload-primary (Observer/WINCH/
            LOAD_CELL) → his payload pads contend;** River (flight-primary) has slack. The
            AM6254 GPADC has no analog rail pin, which is why RSSI is an on-board comparator
            DCD bit, not analog telemetry.
        - [ ] **3 pre-existing in-circuit single-pin stubs (faithfully reproduced, real
            PCB gaps):** `RF_ANT_SW` (T/R-switch antenna common, unconnected), `PA_EMIT`
            (PA emitter-degeneration return), `DDS_FSYNC` (MCP4921 ~LDAC/CS). These are
            missing connections on the as-placed PCB, surfaced now by the schematic — fix on
            the PCB in a routing pass.
        - [ ] Pad 9 (ANT) and pad 13 (3.3V) carry no net — module has no antenna or power path
        - [ ] DIO0–DIO5 (pads 7, 11, 12, 14–16) unassigned pending P1-header GPIO budget decision
        - [ ] Footprint pad size (2.95×1.27 mm) is oversized vs. real RFM95W castellated pads
        - [ ] Footprint physically overlaps CAPE-B IF (JST GH 6P) — needs repositioning
        - [ ] CAPE-B IF (JST GH 6P) connector is still present and fully wired — "replace JST
            with P1+P2 socket rails" has NOT happened; verify whether PB2-P1/P2 sockets already
            carry all 6 of its signals before removing it
    - [ ] EMI spacing verified
    - [ ] Labels and silk arranged for readability
        - [ ] **Still unrouted — 13 nets** (`RF_TX`, `RF_FILT`, `RF_LPF_N2`, `RX_LNA`,
            `TCXO_OUT`, `AFSK_IN`, `AFSK_OUT`, `DDS_CLK`, `DDS_DAT`, `SBUS_OUT`, `RF_RX`,
            `RSSI_RAW`, `UART_RX_MUX`) plus scattered edges within partially-routed nets — sit
            in pockets too tight for a 0.2mm-trace/0.25mm-clearance model to route automatically
            without risking a marginal connection. Needs thinner trace width, B.Cu fallback
            routing, or manual GUI placement.
        - [ ] **Ethernet differential pairs deferred** (`RMII1_*`, `MDIO`, `MDC`, `PHY2_RSTN`,
            `PHY2_INTRN`, `EMMA_ETH_TXP/TXN/RXP/RXN`, `EMMA_ETH_LINE_TXP/TXN/RXP/RXN`) — these are
            differential pairs through the T-ETH isolation transformer; need length/impedance-
            matched routing, not generic pathfinding.
        - [ ] **LoRa SPI bus deferred** (`LORA_RESETN`, `SPI1_MISO/MOSI/CLK/CS_LORA`) — same
            reasoning, lower risk than the Ethernet pairs but not yet attempted.
        - [ ] **`GND2_ETH`/`VCC2_ETH` deferred — confirmed isolated domain (2026-06-20).**
            Per user: ETH-PHY/T-ETH/PB2-P1/P2 were intentionally added to Emma so it can provide
            a second Ethernet port for the TACCO stack (matching Wash's 2-PHY config) and so Emma
            can connect to Ethernet standalone, outside Serenity. `GND2_ETH` is the isolated
            secondary side of the T-ETH transformer — must NOT be bridged to the main GND plane
            (would defeat the isolation). Needs a small isolated copper island/plane, not via-
            stitching to In1.Cu.
    - [ ] **Silk overlap/over-copper cleanup — NOT done, 174 pre-existing warnings.**
        119 `silk_over_copper` + 53 `silk_overlap` + 2 `silk_edge_clearance`, all present
        since before this session and unchanged by it. Emma.md §10 documents a prior partial
        pass (13 pairs) that did not cover this remainder. Each fix needs the same kind of
        spatial verification as the net routing above — comparable scope of effort. Deferred
        to a dedicated session.
    - [ ] Gerbers exported — **not done this session; board has 94 unconnected items and
        174 silk warnings, not yet production-ready. Do not export gerbers for fabrication
        until routing and silk cleanup are complete — see items above.**
- [ ] **TACCO (Cape-B-2) Rev S1 — remove LoRa, add P1+P2 passthrough rails**
    - [ ] **Full sch↔pcb reference-designator remap — REFERRED TO USER (flight-hardware
        risk).** Reconciling to true parity means confirming which schematic symbol maps to
        which PCB footprint across the naming mismatch; guessing that automatically could
        mis-associate footprints on a flight-critical board. Do this as a focused follow-up
        (ideally interactively in KiCad, or with a user-confirmed name-map table), then:
        remove the LoRa block + `J_XCVR` from the schematic to match the PCB, add the P1/P2
        passthrough (TOP) sockets to the schematic, and re-run ERC. Emma's reconciliation
        (above) is the template; TACCO differs only in that its schematic was hand-authored and
        its refs don't already match the PCB the way Emma's did.
    - [ ] EMI spacing verified
    - [ ] Nets and vias fixed
    - [ ] DRC rules checked.
    - [ ] **Verify the already-placed P1/P2 sockets actually carry the same signals the
        schematic's RFM95W/JST-GH nets expect** before removing anything — don't assume the
        PCB-side work is correct just because footprints exist; it was never ERC-checked.
    - Remove RFM95W footprint and all associated SPI routing + LDO supply.
    - Add 2× 20-pin 2.54 mm pass-through socket rails on upper face (upper sockets
        match Emma P1+P2 pinout; lower pins pass through to Cape-A-2 / PB2-I stack).
    - Carry all PB2 P1+P2 signals from lower pins to upper sockets; add 0 Ω options
        on signals consumed by TACCO (Wi-Fi, SiK, I²C, UART) so they are both used and
        passed through.
    - Update silk/fab: "Cape-B-2 Rev S1 — TACCO CN cape"; note Emma header on upper face.
    - Run DRC → zero errors; generate gerbers to `avionics/kicad/gerbers/CAPE-B-2-S1/`.
    - **BLOCKS TACCO + Emma fabrication order.**
- [ ] **FlightEngineer Rev S1 — remove 6 V BEC, add 5 V servo output**
    - Remove TPS54540 6 V/5 A BEC circuit (IC, inductor, output caps, feedback divider,
        Molex Nano-Fit 6 V output connector).
    - Add third TPS54620 5 V/3 A instance for dedicated servo rail (shares 5 V feedback
        reference with avionics BECs; separate output capacitor bank; Molex Nano-Fit
        connector labelled SERVO-5V).
    - Verify 5 V servo current budget: 2× DS3218MG = 2× 500 mA stall = 1.0 A peak;
        3 A rated output provides 3× headroom — adequate.
    - Update silk/fab: "FlightEngineer Rev S1"; update schematic title block.
    - Run DRC → zero errors; generate gerbers to `avionics/kicad/gerbers/FlightEngineer-S1/`.
    - **BLOCKS FlightEngineer fabrication order.**

## §1.2c — PCB Design: Observer (Observer vision/ToF/laser subsystem)

*Master:* [`TODO.md` §1.2c](../TODO.md) — 22 open, 13 done at snapshot.

- [ ] **Confirm PCB fab/assembly house can handle the AM62Ax 484-ball FCBGA/FCCSP package**
    [REF-SENSOR-003] before committing to this SoC in layout — this is a significant assembly
    escalation versus the QFN/SOIC parts used elsewhere in this design. If no viable
    fab/assembly path exists at acceptable cost, escalate to user for an alternative vision
    SoC decision before proceeding with layout. **Still open — the placeholder footprint in
    `gen_vera_pcb.py` does not commit to a real ball-out, so this decision is not yet blocking,
    but must be resolved before the real BGA footprint is authored.
- [x] Shape the Observer PCB to fit in the nose directly behind the faceplate, allowing PCB mounting of laser, camera, and TOF, with EMI hardening.  PCB oriented horizontal with sensors on forward end and network connections on aft end.
- [x] **Source and cite a real Class 3B nose crosshair laser module** — **SUPERSEDED by the
    Class 2 laser unification (§1.2c.4 below, 2026-07-06; `docs/JAYNE_LASER_ANALYSIS.md` Rev A2).**
    The nose is **not** Class 3B: a thin-line green crosshair detected by Observer's own strobed
    camera + frame-difference needs only ~0.2–0.8 mW → **Class 2**. No separate Class 3B nose
    module exists to source — both sites share ONE 520 nm green Class 2 source (per-location
    terminal optic + hardware current limit). The surviving "**do not source** until a real
    IEC 60825-1 datasheet is in REFERENCES.md (REF-IEC-002 pending)" action is the Class 2 item
    in §1.2c.4, not a Class 3B part. Closed in master [`TODO.md`](../TODO.md).
- [ ] Generate production-ready Gerber files to `avionics/kicad/Observer/gerbers/` — **blocked on
    trace routing, real footprints, and silk/DRC cleanup; not meaningful to export gerbers for
    a board that is still using placeholder footprints or is partially routed.**
    - [x] Replace placeholder U1/U2/U3/U5/U_PMIC footprints with real datasheet-approved
        BGA/QFN/VSSOP footprints before fabrication.
    - [ ] Complete full copper routing for all signal nets and power domains.
    - [ ] Resolve any `silk_over_copper`, `silk_overlap`, or `silk_edge_clearance` warnings.
    - [ ] Run KiCad DRC to zero errors after routing and footprint updates.
    - [ ] Export Gerber and drill files to `avionics/kicad/Observer/gerbers/` using KiCad or the
        repository's Gerber workflow once the board is fully routed and verified.
    - [x] Confirm the compact 1.0 × 2.75 in (25.4 × 69.85 mm) `Observer.kicad_pcb` baseline is intentional and, if so,
        back-port the updated board outline/placement into `gen_vera_pcb.py`; otherwise treat
        the script output as a pre-compaction template only.
    - [ ] Render + mesh-verify `head_shell24.scad` (blocked this session; re-attempt).
    - [ ] FreeCAD-verify the proposed pose and pocket-wall clearance against
        `bow_camera_cut`/`bow_tof_cut` — do not hand-derive the bow pod's own
        non-hull-frame local-coordinate transform (documented exception).
    - [ ] Verify against real, non-placeholder U1/U2/U3/U5/U_PMIC footprints once sourced
        (8mm standoff is a starting allowance).
    - [ ] `head_shell24.scad` is a secondary reference (Rev R1) — the Blender-canonical
        pipeline has no head-interior merge script analogous to `merge_cargo_interior.py`
        yet, so these bosses are NOT in the fabrication-ready mesh until one is written.
- [ ] **Flag stale laser bore dimensions:** `LASER_BORE_D=12.5mm`/`LASER_BORE_L=38.0mm` in
    `bow_sensor_pod.scad` are sized for the old 12mm-OD Class 3R laser module. The new
    custom-collimated 520nm **Class 2** green module's real mechanical dimensions are
    undetermined (class corrected 2026-07-06 per `docs/JAYNE_LASER_ANALYSIS.md` Rev A2 — was
    mislabeled "Class 3B" here) — do not reuse these bore numbers without re-measuring against
    the new module's actual datasheet/mechanical drawing.
    - [ ] Render + mesh-verify `cargo_sect_shell24.scad` (blocked this session; re-attempt).
    - [ ] Must also clear the cargo bay door mechanism and Observer (cargo handling) hardware
        — not checked this session.
    - [ ] `cargo_sect_shell24.scad` is a secondary reference — these bosses (and the fixed
        GPS/FPV/River-bay cuts) are NOT in the fabrication-ready mesh until
        `merge_cargo_interior.py` is extended to merge them (see §1.1.1.0a above).
- [ ] **Add `cargo_tof_cut()` and `cargo_laser_cut()` cutter modules** to
    `cargo_sect_shell24.scad`, adjacent to the existing `fpv_cut`/`CARGO_CAM_POS`, nadir-facing
    via `NADIR_ROT` — **no cargo ToF or laser aperture exists today, only the camera cut.**
    Laser spread angle must be re-derived for the cargo spec (3"×3" (76×76mm) at 5 ft (1.5m))
    — do not reuse the nose's 2"×2"-at-50ft optics/bore assumptions. Render + mesh-verify per
    `airframe/CLAUDE.md` after adding.
- [ ] **Local sensor harness (both sites):** J_CAM1/J_CAM2 (MIPI CSI-2, flex/FPC preferred),
    J_TOF (dedicated UART1, twisted pair/ribbon), J_LASER (Q1 gate drive + laser V+, twisted
    pair) — all short point-to-point runs (<75mm) since Observer co-locates with the sensor
    cluster at both sites, unlike the pre-Observer plan of running TFmini-S's UART to Shepherd's
    Room.
- [ ] **External ring harness — nose:** route J_PWR/J_ETH_IN/J_ETH_OUT/J_CANFD aft through the
    open head/cargo mating face to **Shepherd's Room** (nearest bay, PACE-primary Watchdog).
    Open: confirm which existing Ethernet-ring segment Shepherd's stack currently closes, so
    Observer's ring-insertion point and new cable lengths can be fixed.
- [ ] **External ring harness — cargo:** route J_PWR/J_ETH_IN/J_ETH_OUT/J_CANFD through the
    cargo section's open mating faces to the nearest bay. Open: decide **River's Room** vs.
    **Simon's Medbay** as the shorter/more appropriate ring-insertion point (both carry Emma
    boards per the Node Variant Placement table, root `CLAUDE.md`).
- [ ] **FlightEngineer second 5 V rail — cross-tied, mutually fault-tolerant (PLAN, `docs/POWER_
    DISTRIBUTION.md §11.1`).** Add a **third identical TPS54620 BEC channel** (`U_BEC_5V_3` +
    `L_5V3` + `R_FB3` + `C_BEC3_IN/OUT` + `FB_5V3` + `D_OR3` — copy of `U_BEC_5V_1`) feeding
    **RAIL-2 (5V_JAYNE) → `J_JAYNE`** (both Observer boards, ≈ 2.4 A typ / ~4.2 A peak). Existing
    dual-BEC pair = **RAIL-1 (5V_AVIONICS) → `J_5V`**. **Diode-OR cross-tie** the two rails
    (`D_X1`/`D_X2` = 2× MBRD1045CT, same part) via cross-tie fuse `F_X`, plus per-rail fuses
    `F_5V`/`F_VERA`, so each rail is fault-tolerant of the other (regulator-failure backup +
    short isolation). **Same part chain (interchangeable channels); no new part numbers.**
    **Bump set-point 5.3 V → 5.4 V** (re-value the `R_FB` dividers) so a backed-up rail (two
    Schottky drops) stays > 4.75 V PB2-I min. Do schematic-first, then PCB (place `U_BEC_5V_3`
    by the existing pair; SW node in a GND-pour keepout). Number alongside the Rev S1 servo-rail
    change. **Not yet in KiCad.** (Symmetric 2+2 four-channel option in §11.1 if RAIL-2 later
    needs its own internal redundancy.)
- [ ] **Observer 5 V harness:** 18 AWG shielded TP per drop (FlightEngineer → nose bow pod, FlightEngineer → cargo
    nadir mount); 3 A resettable polyfuse per drop; route with each Observer's Ethernet-ring/CAN
    harness. Confirm final run lengths once ring-insertion bays are fixed (§1.2c.3).
- [ ] **Laser — unify to a single 520 nm green source, Class 2 both sites** (retires the
    separate 650 nm red cargo module AND the Rev-A nose Class 3B module). Per-location terminal
    optic sets spread; per-location HARDWARE current limit sets power. **The nose is Class 2
    (≤ 1 mW), NOT Class 3B** — a concentrated ~12 mm dot detected by Observer's camera (strobe +
    frame-difference) needs only ~0.45 mW (`docs/JAYNE_LASER_ANALYSIS.md` Rev A1). This drops the
    Class 3B key-interlock and mechanical shutter entirely.
- [ ] **Both Class 2 caps must be hardware-enforced** (fixed current limit), not firmware-only.
- [ ] **Nose camera strobe + frame-difference detection** (firmware/ISP, TODO.md §4.6) — this
    is what holds the nose at Class 2 in bright sun; laser-sync GPIO/PWM + differencing in the
    AM62A7 ISP. Without it the nose spot is not reliably detected in full daylight.
- [x] *(No longer required — the Rev-A "nose Class 3B mechanical beam-stop/shutter" task is
    retired now that the nose is Class 2.)* Re-open only if a human-at-target-in-full-sun
    visibility requirement is later added (would push the nose back toward 3R/3B).
- [ ] **Do not source** the green diode or either terminal optic until a real datasheet with a
    verified mW rating + IEC 60825-1 class is added to REFERENCES.md (extends the REF-IEC-002
    pending item; the Observer-laser row in "Open Standards Verification Items").

## §1.4 — EMI Hardening Beyond the PCBs (500 W/m^2) &#9733;

*Master:* [`TODO.md` §1.4](../TODO.md) — 43 open, 21 done at snapshot.

- [ ] **PB2-I + Wash Enclosure** (Shepherd's Room / Inara's Shuttle — no Emma board):
    - [ ] Confirm internal clearance for PB2-Industrial + Cape-A-2 stack height against
        the FAR-CAGE-AV placeholder envelope (76×56×88 mm, §1.1.5).
    - [ ] Cut-outs for GPS/IMU/barometer sensor leads, ToF array cabling, servo/ESC
        connectors, and the microSD log slot — each cut-out gets its own FAR-FT-PANEL
        feedthrough or grommet, not an open hole.
    - [ ] Mount FAR-FAN-40 + FAR-EMI-VENT-40 on the low-pressure side of the enclosure;
        verify intake/exhaust path does not create a direct RF leakage slot.
    - [ ] Bond enclosure to chassis ground via FAR-BOND-STRAP (single point, no loop).
- [ ] **PB2-I + TACCO Enclosure** (all 4 bays — Cape-B-2, plus Emma in River's Room /
    Simon's Medbay only):
    - [ ] Confirm internal clearance for PB2-Industrial + Cape-B-2 (+ Emma where fitted)
        stack height against the FAR-CAGE-AV placeholder envelope.
    - [ ] Cut-outs for CAN FD/RS-485/Ethernet/MIL-1553 connectors, SMA antenna feeds
        (WiFi/SiK/LoRa per §1.4.2), and the microSD log slot — feedthrough or grommet
        per cut-out.
    - [ ] River's Room / Simon's Medbay variant: add the LoRa + 49 MHz SMA feedthrough
        pair for Emma; Shepherd's Room / Inara's Shuttle variant omits these.
    - [ ] Mount FAR-FAN-40 + FAR-EMI-VENT-40; bond via FAR-BOND-STRAP.
    - [ ] **Zigbee 2.4 GHz antenna mount — BLOCKED, hardware gap confirmed; antenna
        strategy decided 2026-06-22 (with user).** TACCO (Cape-B-2) Rev S has no Zigbee
        transceiver, antenna filter chain, or SMA pad (the CC2652R7 Zigbee radio exists
        only in the archived COMMS-HAT-1 design, not in the current Rev S Cape-B-2
        schematic) — **no antenna can be mounted for hardware that does not exist on
        the board**, so this remains a genuine PCB scope gap, not just a placement
        question. **Decision:** rather than a time-shared coexistence switch, split
        the existing dual-band Wi-Fi antenna by frequency instead of by time —
        **restrict WL1837MOD Wi-Fi to 5 GHz only** (already the spec for the Wi-Fi
        whip mounts above) and feed the freed 2.4 GHz path to the future CC2652R7
        Zigbee module through a passive **2.4/5 GHz diplexer** ahead of one shared
        broadband antenna. Because Wi-Fi and Zigbee no longer overlap in frequency,
        this needs no `RF_NCOEX` coexistence arbitration and no switching — both
        radios can transmit/receive simultaneously through the diplexer, unlike a
        switched-antenna approach. The diplexer (and the antenna it feeds) remains a
        single passive point of failure shared between the two radios, but a passive
        component is materially more reliable than an active coexistence switch, and
        Wi-Fi/Zigbee are not PACE failover partners of each other (unlike River/Simon's
        49 MHz link, sharing here doesn't undermine the redundancy mandate).
        Still open: which bay carries the Zigbee module once added, diplexer part
        selection, and Cape-B-2 schematic work to add the CC2652R7 RF chain.
        **Cross-reference added to §1.2a as a tracked PCB scope gap.**
    - [ ] **Verify the 6 dorsal mount stations (Shepherd ×2, Inara ×2, River's LoRa whip,
        Simon's SiK whip) in FreeCAD against the baked hull** — confirm ≥ 30 mm
        antenna-to-antenna spacing is actually achievable on the as-built dorsal skin at
        each bay's station, and that no mount collides with an access-panel cover
        (§1.1.1.0a), the bow sensor pod (§1.1.1.1a), or the dorsal antenna fin
        (`dorsal_antenna_fin.stl`). **BLOCKS dorsal antenna mount printing.**
    - [ ] **Verify the 2 flank mount lines (River's 49 MHz, port; Simon's 49 MHz,
        starboard) in FreeCAD against the cargo clamshell door swing envelope** — see
        the dedicated sub-task under "Second 49 MHz antenna" below.
        **BLOCKS flank antenna mount printing.**
    - [ ] **Verify the exact shoulder-height Z offset in FreeCAD against the cargo
        door's 180°-open envelope** (door panel width from the hinge line) at every
        station along sta 120–580 mm, not just within the door bay's own Y-span —
        confirm port and starboard mount lines clear the door on both sides.
        **BLOCKS bonding either antenna's posts.**
    - [ ] **Confirm the port/starboard mount line also clears the wing roots** (wings
        attach at the cargo section's lateral walls, `CLAUDE.md`) — the flank line
        passes close to this area within the cargo section.
        **BLOCKS Simon's 49 MHz antenna fabrication; BLOCKS River's antenna relocation.**
    - [ ] **Bench-verify isolation between the two 49 MHz antennas** (River's port,
        Simon's starboard) before first flight — confirm neither antenna's feedpoint
        impedance shifts unacceptably with the other antenna present, and that
        simultaneous Emma TX on one does not desense the other's receiver beyond an
        acceptable margin. Use the same HDOP-with-TX-active bench test already specified
        for `POST-FWD-49` as a model.
- [ ] **CAN FD** — specify bus topology (linear trunk vs. star), termination (120 Ω at each
    physical end), node tap spacing, and connector pinout per node; cross-reference the
    CAN_H/CAN_L footprint pinout already fixed on Wash (§1.2).
- [ ] **RS-485** — specify daisy-chain topology, termination, and connector pinout per node;
    cross-reference the RS485_A/B footprint pinout already fixed on Wash (§1.2).
- [ ] **MIL-STD-1553B** — specify bus controller / remote terminal wiring per node role
    (§4.2 "MIL-STD-1553B RT implementation," §4.3 "MIL-STD-1553B BC/RT tasks"); stub length
    and transformer-coupling placement per node, matching the 1553-XFM coupling already
    partially netted on Wash (§1.2).
- [ ] **Ethernet** — specify CPSW3G ring topology (node-to-node order), cable category, and
    connector pinout; cross-reference the 100 Ω ±10% MDI impedance-controlled traces already
    specified on Wash/TACCO (§1.2) and the RSTP ring management firmware task (§4.3).
- [ ] **UART** — specify wiring for GPS (u-blox M10Q NMEA/UBX, §4.2), SBUS-equivalent
    (§1.2 "Add SBUS/UART DIP switch to Wash"), and any inter-cape UART links.
- [ ] **I2C** — specify wiring for IMU/barometer (ICM-42688-P, BMP388/390 — note these are
    SPI per §4.2, verify bus assignment), ToF array mux (TCA9548A) and XSHUT GPIO expander
    (MCP23008), and the `U-GPIO` PCA9555DB expander already added to Wash (§1.2).
- [ ] **BDSHOT/DSHOT (ESC telemetry)** — specify wiring for the ESC-PWM connector (DSHOT0–3,
    JST-GH 5-pin, already defined on Wash §1.2) and BDSHOT600 telemetry return path on PRU-ICSS
    (§4.2 "EDF ESC PID governor").
- [ ] **PWM** — specify wiring for nacelle tilt servo control (EHRPWM/PRU, §4.2 "Nacelle tilt
    servo PWM generation") and the SERVO-PWM 1×8 connector pinout already defined on Wash
    (§1.2).
- [ ] **Add FlightEngineer/battery boss pattern to `middle_canonical_shell24.scad`.**
    Boss posts: 4× M3 at (±55 mm X) × (±25 mm Z) from X=−190 mm keel centre for battery tray.
    FlightEngineer PDB: 4× M3 boss posts at X≈−205 mm, Z=CZ±25 mm. Both on keel interior face (+Y rail).
    Verify boss positions clear keel CF flat bar (6×3 mm) and ring frame station notches in slicer.
- [ ] **Add ventral battery-swap hatch cut to `middle_canonical_shell24.scad`.**
    120×60 mm belly cut centred at X=−190 mm; 2 mm shoulder lip; same pattern as avionics panels.
    **BLOCKS Phase 1 foam pour** (void former must clear hatch zone before foam pour).
- [ ] **Create `kaylee_battery_tray.scad`.**
    CF-PETG slide-in rail guide tray for 6S LiPo 155×52×36 mm; M3 attachment to boss posts;
    two captive Velcro strap slots; XT90 connector exit cutout on AFT face.
    **Add to Phase 0 print schedule.**
- [ ] **Create `kaylee_pdb_tray.scad`.**
    CF-PETG mounting tray for FlightEngineer PDB (80×60 mm footprint); M3 boss attachment;
    XT90 input pigtail route-through; 4× XT30 output ports facing AFT (toward ESC conduits).
    **Add to Phase 0 print schedule.**
    - [ ] **DRC accepted violations (document only — not fixable without PCB re-architecture):**
        - [ ] 16 clearance violations at 0.15 mm: INA226 MSOP-10 adjacent pads (pins 3/4) at 0.5 mm pitch
        inherently violate 0.2 mm PGND/POWER_5V class rule; IPC-2221B allows ≥ 0.1 mm for ≤ 31 V
        - [ ] 77 courtyard overlaps: dense 90×65 mm layout; 3D bodies do not conflict; no manufacturing impact
        - [ ] 59 lib_footprint_mismatch: all footprints are inline in .kicad_pcb (not library copies); expected
        - [ ] 33 silk_over_copper / 26 silk_overlap / 2 silk_edge_clearance: cosmetic; board is fab-ready
        - [ ] 8 lib_footprint_issues: inline footprints; not KiCad library-linked; expected
        - [ ] 181 unconnected_items: traces not yet routed (power planes on In1/In2.Cu are correct)
    - [ ] **FlightEngineer PCB — remaining layout tasks (BLOCKS fabrication):**
        - [ ] Manually place in KiCad: CM_ESC1–4 (INA226 shunt caps), C_DEC1–4 (ESC decoupling), Section F
                    (BQ76930, J_BAL, R_BAL1–6, C_CAP, J_NTC, C_NTC) — area x=62–88, y=50–65 recommended
        - [ ] Manually place: J_SHLD_5V, J_SHLD_6V, J_SHLD_I2C, J_SHLD_ALERT chassis shield lugs
        - [ ] Route all traces; verify 4 oz Cu pour on VBAT/PGND power planes (In2.Cu / In1.Cu)
        - [ ] Add BQ76930 thermal pad (TSSOP-30 PowerPAD) to footprint — currently missing from gen_kaylee_pcb.py
        - [ ] Verify XT30 connectors (J_ESC1–4) courtyard clears board edge on left side
        - [ ] Verify size and weight: PCB target ≤ 90×65 mm, ≤ 0.110 lbm (≤ 50 g)
- [ ] **Update REVN_BUILD_GUIDE_24IN.md Phase 1** to include FlightEngineer + battery tray installation
    in the pre-foam-pour checklist. Battery tray and hatch must be installed and hatch zone
    masked before the foam pour step.

## §0.6 — IEC 62368-1 PCB Layout Isolation Verification &#9733;

*Master:* [`TODO.md` §0.6](../TODO.md) — 0 open, 3 done at snapshot.

*No open items — baseline complete; retained for traceability.*

## §1.3 — PCB Design: XCVR-49MHZ-1 (SUPERSEDED)

*Master:* [`TODO.md` §1.3](../TODO.md) — 0 open, 5 done at snapshot.

*No open items — baseline complete; retained for traceability.*

## §1.2 — PCB Design: Cape-A-1 and Cape-B-1 (archived)

*Master:* [`TODO.md` §1.2](../TODO.md) — 0 open, 2 done at snapshot.

*No open items — baseline complete; retained for traceability.*

## §4.1 — Firmware: Completed / carry-forward

*Master:* [`TODO.md` §4.1](../TODO.md) — 0 open, 6 done at snapshot.

*No open items — baseline complete; retained for traceability.*

## §4.2 — FC Node (Wash) Firmware &#9733;

*Master:* [`TODO.md` §4.2](../TODO.md) — 38 open, 2 done at snapshot.

- [ ] **EDF ESC PID governor** — BDSHOT600 telemetry input on PRU-ICSS, EHRPWM output to ESCs, CAN FD cross-node synchronisation. Targets: settle <200ms, overshoot <5%; equalization |RPM_FWD − RPM_AFT| <100 RPM; fault latch on overtemp/overcurrent (no auto-recovery, GCS ack required).
    - [ ] PRU-ICSS BDSHOT600 telemetry decoder (RPM, voltage, current, temp frames).
    - [ ] EHRPWM throttle output driver with `governor_config.h` k-coefficient (§4.1, already calibrated).
    - [ ] CAN FD cross-node RPM sync message (fwd/aft pairing across River/Simon).
    - [ ] PID tuning bench test against `governor_cal.py` thrust-stand data; verify settle/overshoot/equalization targets above.
    - [ ] Overtemp/overcurrent fault-latch unit test (no auto-recovery path).
- [ ] **Nacelle tilt servo PWM generation** — EHRPWM or PRU; travel limits −5°/140° enforced in firmware; symmetric 2° tracking both nacelles.
    - [ ] EHRPWM/PRU servo output driver with firmware-enforced travel limits (−5°/140°).
    - [ ] Symmetric tracking control loop (port/stbd nacelle ≤2° divergence).
    - [ ] Bench test: command full sweep, verify limit clamping and tracking error budget.
- [ ] **IMU / barometer sensor fusion** — ICM-42688-P (SPI), BMP388/BMP390 (SPI); complementary or Kalman filter for attitude; altitude hold PID using barometric altitude + GPS.
    - [ ] ICM-42688-P SPI driver (accel/gyro read, calibration/bias removal).
    - [ ] BMP388/BMP390 SPI driver (pressure/altitude read).
    - [ ] Attitude filter (complementary or Kalman) fusing IMU + barometer.
    - [ ] Altitude-hold PID using fused barometric + GPS altitude.
    - [ ] Bench test: static and bench-rotation attitude accuracy check.
- [ ] **ToF sensor array management** — VL53L5CX ×6 per node via TCA9548A I²C mux; XSHUT sequencing via MCP23008; OA fusion (Array A + Array B cross-check); halt at 1.0m clearance.
    - [ ] TCA9548A I²C mux driver (channel select for 6× VL53L5CX per node).
    - [ ] MCP23008 XSHUT sequencing driver (sensor power-up ordering, address conflict avoidance).
    - [ ] VL53L5CX 8×8 ranging driver and per-sensor data aggregation.
    - [ ] Array A / Array B cross-check fusion logic; halt-at-1.0m / resume-at-1.5m hysteresis (matches §4.4 "OA integration").
    - [ ] Bench test: known-distance target sweep, verify halt/resume thresholds.
- [ ] **u-blox M10Q GNSS integration** — UART NMEA/UBX parse; position fix broadcast on CAN FD; HDOP gating (≤1.5 for valid position); multi-node position cross-check (≤2m disagreement threshold).
    - [ ] UART NMEA/UBX parser (position, velocity, HDOP, fix-type fields).
    - [ ] HDOP gating logic (reject fix if HDOP >1.5).
    - [ ] CAN FD position-fix broadcast frame.
    - [ ] Multi-node cross-check consumer (flag/exclude outliers >2m, feeds §4.4 "GPS cross-check").
    - [ ] Bench/field test: static fix HDOP and 4-node position agreement.
- [ ] **MIL-STD-1553B RT implementation** — PRU-ICSS Manchester II encoder/decoder; RT address assignment per node role; BC arbitration on FC1 and FC2.
    - [ ] PRU-ICSS Manchester II encode/decode driver.
    - [ ] RT address assignment table per node role (FC1–FC4).
    - [ ] BC arbitration logic for FC1 (primary) / FC2 (standby).
    - [ ] Bench test against the 1553-XFM transformer coupling hardware (§1.2 "Wire the MIL-1553 connector + transformer").
- [ ] **TPM-bound attestation** — SLB9670 TPM 2.0 HMAC on all outbound flight-critical CAN FD messages; pcrs extend on each boot; boot measurement chain.
    - [ ] SLB9670 TPM 2.0 driver (HMAC key derivation, PCR extend calls).
    - [ ] Boot measurement chain (PCR extend at each boot stage).
    - [ ] Outbound CAN FD HMAC signing hook for flight-critical message classes.
    - [ ] Bench test: tamper/replay rejection unit test against signed vs. unsigned frames.

## §4.3 — CN Node (Zoe) Firmware &#9733;

*Master:* [`TODO.md` §4.3](../TODO.md) — 36 open, 0 done at snapshot.

- [ ] **CAN FD heartbeat and telemetry forwarding** — broadcast 0x001–0x008 node health frames; relay MAVLink telemetry from elected FC master to SiK GCS link.
    - [ ] 0x001–0x008 node health frame broadcaster (per-node heartbeat content/period).
    - [ ] MAVLink telemetry relay path: FC master CAN FD → CN master → SiK GCS link.
    - [ ] Bench test: heartbeat timeout detection feeding §4.4 "Node role election protocol."
- [ ] **MIL-STD-1553B BC/RT tasks** — BC on CN1 (standby), RT on CN2–CN4; mirror FC bus controller arbitration.
    - [ ] BC standby logic on CN1 (mirrors FC1/FC2 arbitration, §4.2).
    - [ ] RT implementation on CN2–CN4 (shares PRU-ICSS Manchester II driver with §4.2).
    - [ ] Bench test against 1553-XFM transformer coupling hardware (§1.2).
- [ ] **RS-485 inter-board messaging** — structured message format (header/payload/CRC); inter-node command and status relay.
    - [ ] Define structured frame format (header/payload/CRC) shared across all 8 nodes.
    - [ ] Driver for the RS485_A/B footprint pinout already fixed on Wash/TACCO (§1.2).
    - [ ] Bench test: CRC-reject malformed frame, command/status round-trip between two nodes.
- [ ] **Ethernet RSTP ring management** — CPSW3G bridge configuration; RSTP fast-failover (<1s) verification; ring segment health monitoring.
    - [ ] CPSW3G bridge configuration for the 8-node ring topology (§1.4.3).
    - [ ] RSTP fast-failover implementation and timer tuning.
    - [ ] Ring segment health monitoring/reporting hook (feeds CAN FD heartbeat above).
    - [ ] Bench test: physically break one ring segment, verify <1s failover.
- [ ] **Signed-log write via CPLD write-blocker** — log records written as read-only-append through ATF16V8BQL latch interface; NOR flash (W25Q128JV) circular buffer for overflow.
    - [ ] ATF16V8BQL CPLD write-blocker interface driver (enforces append-only).
    - [ ] microSD log writer (primary store) per node's write-blocked card.
    - [ ] W25Q128JV NOR flash circular buffer driver for overflow when microSD is full/unavailable.
    - [ ] Bench test: attempt out-of-order/overwrite write, verify CPLD blocks it.
- [ ] **TPM-bound HMAC on all outbound AX.25 payloads** — each 49 MHz (Part 15 §15.235) packet includes HMAC-SHA256 computed from SLB9670 stored key; receiver nodes verify before acting.
    - [ ] SLB9670 stored-key HMAC-SHA256 signer for outbound AX.25/49 MHz frames (Emma boards, River/Simon).
    - [ ] Receiver-side verification gate (discard unsigned/invalid before acting, mirrors §4.4 "Security message signing").
    - [ ] Bench test: signed/unsigned/corrupted-signature frame acceptance matrix.
- [ ] **Cargo control** — DRV8833 winch H-bridge, HX711 load cell (payload weight sensing), SG90 door and release servos; state machine: IDLE → DEPLOY → DELIVERED → RETRACT → LATCHED.
    - [ ] DRV8833 H-bridge winch driver.
    - [ ] HX711 load-cell driver (payload weight sensing, overload cutoff).
    - [ ] SG90 door + release servo driver.
    - [ ] State machine implementation: IDLE → DEPLOY → DELIVERED → RETRACT → LATCHED, with fault states.
    - [ ] Bench test: full cycle with simulated payload load, verify HX711 cutoff and state transitions.
- [ ] **MAVLink routing configuration** — mavlink-router config: elected CN master routes FC master telemetry to all 4 radio links (SiK, LoRa, Wi-Fi, 49 MHz (Part 15 §15.235) backup).
    - [ ] mavlink-router config file per CN role (master vs. standby).
    - [ ] Per-link output adapter: SiK, LoRa (Emma), Wi-Fi, 49 MHz (Part 15 §15.235) (Emma, backup).
    - [ ] Bench test: verify telemetry reaches Malcolm GCS over each of the 4 links independently.

## §4.4 — Both Nodes (shared firmware) &#9733;

*Master:* [`TODO.md` §4.4](../TODO.md) — 22 open, 0 done at snapshot.

- [ ] **Node role election protocol** — CAN FD priority arbitration at boot; lowest node-ID wins master role; automatic failover on heartbeat timeout (100ms); FC master and CN master elected independently.
    - [ ] Boot-time CAN FD priority arbitration (lowest node-ID wins, per PACE table in CLAUDE.md).
    - [ ] Independent FC-master / CN-master election state machines.
    - [ ] Failover trigger on 100ms heartbeat timeout (consumes §4.3 heartbeat broadcast).
    - [ ] Bench test: kill the current master, verify failover to next PACE tier within timeout.
- [ ] **Autonomous navigation** — 3-waypoint GPS mission execution; altitude hold ±0.3m; waypoint radius 2m; RTL on any link loss >5s.
    - [ ] Waypoint mission sequencer (3-waypoint minimum viable mission).
    - [ ] Altitude-hold integration with §4.2 barometric/GPS altitude PID.
    - [ ] Waypoint-radius capture logic (2m) and RTL trigger on link loss >5s.
    - [ ] Field test: full 3-waypoint mission with deliberate link-loss RTL trigger.
- [ ] **OA integration** — ToF halt trigger feeds into navigation; velocity command zeroed within 1.0m of obstacle; resumes when clear.
    - [ ] Navigation-layer consumer for §4.2 ToF array halt/resume signal.
    - [ ] Velocity command zeroing at 1.0m clearance; resume logic at 1.5m clearance.
    - [ ] Bench/field test: approach a target obstacle, verify halt/resume hysteresis in flight.
- [ ] **GPS cross-check** — 4 GPS receivers (one per FC node); positions averaged; outlier >2m flagged and excluded from blend.
    - [ ] Multi-node position collection (4× u-blox M10Q via §4.2 CAN FD broadcast).
    - [ ] Averaging/blend algorithm with outlier exclusion (>2m disagreement).
    - [ ] Bench test: inject a synthetic outlier fix, verify exclusion from blend.
- [ ] **Security message signing** — every inter-node CAN FD message signed; unauthenticated messages discarded; signing key material bound to node TPM endorsement key.
    - [ ] CAN FD message signing hook bound to each node's TPM endorsement key (SLB9670, §4.2).
    - [ ] Receiver-side verification gate; discard unauthenticated frames before acting.
    - [ ] Bench test: inject unsigned/forged frame on the bus, verify it is discarded and logged.

## §4.6 — Observer Node Firmware (Observer vision subsystem)

*Master:* [`TODO.md` §4.6](../TODO.md) — 15 open, 0 done at snapshot.

- [ ] **MIPI CSI-2 camera sensor bring-up** — select an actual camera sensor module compatible
    with AM62Ax's MIPI CSI-2 v1.3 / D-PHY 1.2 input [REF-SENSOR-003]; port or write the V4L2
    sensor driver (device tree camera node, I²C control interface, sensor-specific register init).
- [ ] **VPAC/ISP pipeline configuration** — tune the 7th-gen ISP (exposure, white balance, lens
    shading, noise reduction) for outdoor daylight FPV use via TI's open-source ISP tuning tools.
- [ ] **H.264/H.265 hardware encoder pipeline** — GStreamer pipeline using the AM62Ax hardware
    encoder; target bitrate/latency suitable for real-time FPV over the Ethernet ring.
- [ ] **Kernel/BSP integration** — confirm TI's open-source Linux BSP version target, document
    kernel version and any patches required; this is explicitly **not** an OpenIPC port (TI
    silicon is not OpenIPC-supported — see REFERENCES.md "Removed / Superseded Citations").
- [ ] **Bench test:** verify stable H.264/H.265 stream from a live camera sensor to a
    development-host GStreamer receiver before integrating with the Ethernet ring.
- [ ] **MCAN (CAN-FD) driver bring-up** — native hardware peripheral [REF-SENSOR-004]; no
    software PIO synthesis required (unlike an RP2350-based design).
- [ ] **TFmini-S UART driver** — reuse driver approach already planned for Shepherd `serenity-fc`
    (see §1.1.1.1a); republish ToF range data over both CAN-FD and the Ethernet ring.
- [ ] **KSZ9477 Ethernet switch management driver** [REF-SENSOR-005] — confirm HSR/PRP hardware
    redundancy is correctly configured (verify against AN3474) so ring failover requires no
    software topology management on the PocketBeagle 2 nodes.
- [ ] **Laser GPIO driver (both sites Class 2 — `docs/JAYNE_LASER_ANALYSIS.md` Rev A2):**
    GPIO-enable with pull-down-default-off + heartbeat-loss interlock (drop GPIO low if
    Ethernet ring AND CAN-FD both lose master-FC heartbeat) [REF-IEC-002 §5.4]. The Class 2 cap
    is hardware-enforced, so no key-interlock/shutter is required; `LASER_KEY_IN`/`LASER_IND`
    are optional defense-in-depth. (Supersedes the earlier Cargo-3R / Nose-3B split.)
- [ ] **Laser strobe + crosshair-metrology routine (AM62A7 ISP):** strobe the laser via a
    laser-sync GPIO/PWM and temporally difference (laser-on − laser-off) to extract the
    crosshair in daylight; sub-pixel-fit the crosshair lines and compute detected-object
    **size** = (obj_px/cross_px)·2R·tan(θ/2) and **tilt** from arm foreshortening, using the
    boresighted TFmini-S range R (`docs/JAYNE_LASER_ANALYSIS.md §4.4`). Publish size/orientation
    with the signed telemetry below.
- [ ] **SPI driver to Infineon SLB9670 TPM** — reuse the existing TPM driver approach already
    used fleet-wide on Wash/TACCO nodes rather than writing a new one from scratch.
- [ ] **Signed telemetry:** TPM-signed HMAC or ECDSA signature on all ToF/laser-state packets
    published over CAN-FD and Ethernet, per Zero Trust policy [REF-NIST-001 §2.1].
- [ ] **Bench test:** verify Observer node publishes signed ToF range + laser-state + video stream
    to at least one PocketBeagle 2 node over both CAN-FD and Ethernet independently.
- [ ] **Ring failure test:** break the Ethernet ring at a point other than Observer; verify KSZ9477
    HSR/PRP failover completes with no observable video interruption.
- [ ] **Laser safety interlock test (nose only):** verify laser GPIO drops low within the
    heartbeat-loss window when Ethernet ring and CAN-FD are both disconnected from Observer.

## §1.8 — Names

*Master:* [`TODO.md` §1.8](../TODO.md) — 0 open, 9 done at snapshot.

*No open items — baseline complete; retained for traceability.*

## §1.9 — Avionics Workload Balancing

*Master:* [`TODO.md` §1.9](../TODO.md) — 0 open, 0 done at snapshot.

*No open items — baseline complete; retained for traceability.*

## Procurement (master §2.x — BOM tables)

- [`TODO.md` §2.4 — Avionics (Phase 6, 4-node minimum viable)](../TODO.md)
- [`TODO.md` §2.5 — Avionics (Phase 7, remaining 4 nodes + ToF arrays)](../TODO.md)

KiCad DRC/ERC workflow and cape naming are governed by [`avionics/CLAUDE.md`](CLAUDE.md). Ground-station (Malcolm) firmware is in [`gcs/TODO.md`](../gcs/TODO.md).

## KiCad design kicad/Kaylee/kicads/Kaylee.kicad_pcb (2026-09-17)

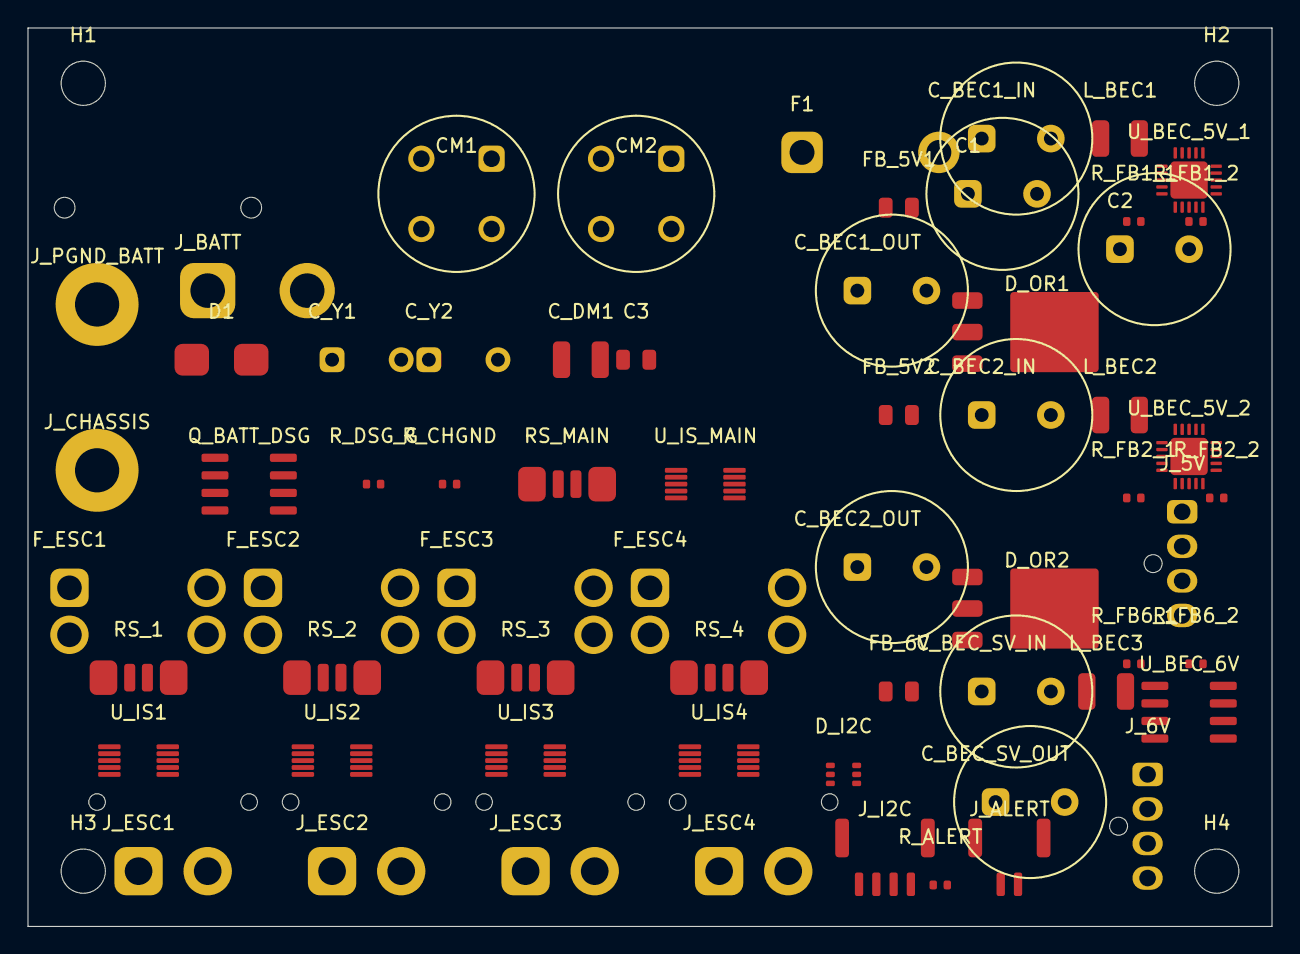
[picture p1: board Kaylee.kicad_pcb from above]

Board: 4 copper layers, 90.0 x 65.0 mm, 67 parts (0 on the bottom side), 36 nets, no tracks yet.

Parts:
C1, C2: 220uF/35V; CP_Radial_D10.0mm_P5.00mm
C3: 100nF/50V; C_0805_2012Metric
CM1, CM2: WE-SL5_7440640500; CMC_WE-SL5_7440640500
C_BEC1_IN, C_BEC1_OUT, C_BEC2_IN, C_BEC2_OUT: 100uF/50V; CP_Radial_D10.0mm_P5.00mm
C_BEC_SV_IN: 100uF/50V; CP_Radial_D10.0mm_P5.00mm
C_BEC_SV_OUT: 100uF/50V; CP_Radial_D10.0mm_P5.00mm
C_DM1: 10uF/50V; L_1210_3225Metric
C_Y1, C_Y2: 4.7nF/250V_Y2; C_Disc_D4.3mm_W1.9mm_P5.00mm
D1: SMBJ33CA; D_SMB
D_I2C: PRTR5V0U2X; SOT-363_SC-70-6
D_OR1, D_OR2: MBRD1045CT; TO-252-3_TabPin2
F1: FuseHolder_MAXI_150A; FuseHolder_MAXI_PCB
FB_5V1, FB_5V2, FB_6V: WE-742792612; C_0805_2012Metric
F_ESC1, F_ESC2, F_ESC3, F_ESC4: FuseHolder_Mini_40A; Fuseholder_Blade_Mini_Keystone_3568
H1, H2, H3, H4: M3; MountingHole_3.2mm_M3
J_5V: NanoFit-4P_5V; Molex_Nano-Fit_105309-xx04_1x04_P2.50mm_Vertical
J_6V: NanoFit-4P_6V; Molex_Nano-Fit_105309-xx04_1x04_P2.50mm_Vertical
J_ALERT: JST-GH_2P_ALERT; JST_GH_BM02B-GHS-TBT_1x02-1MP_P1.25mm_Vertical
J_BATT: XT60PW-F; AMASS_XT60PW-F_1x02_P7.20mm_Horizontal
J_CHASSIS: M3_Lug; MountingHole_3.2mm_M3_Pad_Via
J_ESC1: XT30PW-F_ESC1; AMASS_XT30PW-F_1x02_P2.50mm_Horizontal
J_ESC2: XT30PW-F_ESC2; AMASS_XT30PW-F_1x02_P2.50mm_Horizontal
J_ESC3: XT30PW-F_ESC3; AMASS_XT30PW-F_1x02_P2.50mm_Horizontal
J_ESC4: XT30PW-F_ESC4; AMASS_XT30PW-F_1x02_P2.50mm_Horizontal
J_I2C: JST-GH_4P_I2C; JST_GH_BM04B-GHS-TBT_1x04-1MP_P1.25mm_Vertical
J_PGND_BATT: M3_Lug; MountingHole_3.2mm_M3_Pad_Via
L_BEC1, L_BEC2, L_BEC3: WE-744314100_10uH; L_1210_3225Metric
Q_BATT_DSG: AON6556; SOIC-8_3.9x4.9mm_P1.27mm
RS_1, RS_2, RS_3, RS_4: 1mOhm_Kelvin_2512; R_Shunt_CSS2H_2512K
RS_MAIN: 1mOhm_Kelvin_2512; R_Shunt_CSS2H_2512K
R_ALERT: 2.2k; R_0402_1005Metric
R_CHGND: 0R; R_0402_1005Metric
R_DSG_G: 10k; R_0402_1005Metric
R_FB1_1, R_FB2_1, R_FB6_1: 100k; R_0402_1005Metric
R_FB1_2, R_FB2_2: 22.1k; R_0402_1005Metric
R_FB6_2: 30.1k; R_0402_1005Metric
U_BEC_5V_1, U_BEC_5V_2: TPS54620RGYT; Texas_RGP0020D_VQFN-20-1EP_4x4mm_P0.5mm_EP2.7x2.7mm
U_BEC_6V: TPS54540DDAR; SOIC-8_3.9x4.9mm_P1.27mm
U_IS1: INA226_0x40; MSOP-10_3x3mm_P0.5mm
U_IS2: INA226_0x41; MSOP-10_3x3mm_P0.5mm
U_IS3: INA226_0x42; MSOP-10_3x3mm_P0.5mm
U_IS4: INA226_0x43; MSOP-10_3x3mm_P0.5mm
U_IS_MAIN: INA226_0x44; MSOP-10_3x3mm_P0.5mm

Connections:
+5V: D_I2C.6, D_OR1.2, D_OR2.2, J_5V.3, J_5V.4, J_I2C.2, R_ALERT.1, U_IS1.4, U_IS2.4, U_IS3.4, U_IS4.4, U_IS_MAIN.4
+6V: C_BEC_SV_OUT.1, J_6V.3, J_6V.4, R_FB6_1.1, U_BEC_6V.6
BEC1_PRE_OR: C_BEC1_OUT.1, D_OR1.1, R_FB1_1.1, U_BEC_5V_1.11
BEC1_SW: L_BEC1.2, U_BEC_5V_1.5, U_BEC_5V_1.6
BEC1_VIN_F: C_BEC1_IN.1, FB_5V1.2, L_BEC1.1, U_BEC_5V_1.1, U_BEC_5V_1.15, U_BEC_5V_1.16, U_BEC_5V_1.17, U_BEC_5V_1.18, U_BEC_5V_1.19, U_BEC_5V_1.20
BEC2_PRE_OR: C_BEC2_OUT.1, D_OR1.3, D_OR2.1, D_OR2.3, R_FB2_1.1, U_BEC_5V_2.11
BEC2_SW: L_BEC2.2, U_BEC_5V_2.5, U_BEC_5V_2.6
BEC2_VIN_F: C_BEC2_IN.1, FB_5V2.2, L_BEC2.1, U_BEC_5V_2.1, U_BEC_5V_2.15, U_BEC_5V_2.16, U_BEC_5V_2.17, U_BEC_5V_2.18, U_BEC_5V_2.19, U_BEC_5V_2.20
BEC6V_SW: L_BEC3.2, U_BEC_6V.8
BEC6V_VIN_F: C_BEC_SV_IN.1, FB_6V.2, L_BEC3.1, U_BEC_6V.2, U_BEC_6V.3, U_BEC_6V.4
CHASSIS: C_Y1.2, C_Y2.2, R_CHGND.2
DSG_GATE: Q_BATT_DSG.8, R_DSG_G.1
ESC1_FUSED: F_ESC1.2, RS_1.1, U_IS1.10
ESC1_RS_OUT: J_ESC1.1, RS_1.4
ESC1_SNS_N: RS_1.3, U_IS1.2
ESC1_SNS_P: RS_1.2, U_IS1.1
ESC2_FUSED: F_ESC2.2, RS_2.1, U_IS2.10
ESC2_RS_OUT: J_ESC2.1, RS_2.4
ESC2_SNS_N: RS_2.3, U_IS2.2
ESC2_SNS_P: RS_2.2, U_IS2.1
ESC3_FUSED: F_ESC3.2, RS_3.1, U_IS3.10
ESC3_RS_OUT: J_ESC3.1, RS_3.4
ESC3_SNS_N: RS_3.3, U_IS3.2
ESC3_SNS_P: RS_3.2, U_IS3.1
ESC4_FUSED: F_ESC4.2, RS_4.1, U_IS4.10
ESC4_RS_OUT: J_ESC4.1, RS_4.4
ESC4_SNS_N: RS_4.3, U_IS4.2
ESC4_SNS_P: RS_4.2, U_IS4.1
MAIN_SNS_N: RS_MAIN.3, U_IS_MAIN.2
MAIN_SNS_P: RS_MAIN.2, U_IS_MAIN.1
PDB_ALERT_N: J_ALERT.2, R_ALERT.2, U_IS1.7, U_IS2.7, U_IS3.7, U_IS4.7, U_IS_MAIN.7
PDB_SCL: D_I2C.4, J_I2C.3, U_IS1.6, U_IS2.6, U_IS3.6, U_IS4.6, U_IS_MAIN.6
PDB_SDA: D_I2C.5, J_I2C.4, U_IS1.5, U_IS2.5, U_IS3.5, U_IS4.5, U_IS_MAIN.5
PGND: C1.2, C2.2, C3.2, CM1.3, CM1.4, CM2.3, CM2.4, C_BEC1_IN.2, C_BEC1_OUT.2, C_BEC2_IN.2, C_BEC2_OUT.2, C_BEC_SV_IN.2, C_BEC_SV_OUT.2, C_DM1.2, C_Y2.1, D1.1, D_I2C.1, J_5V.1, J_5V.2, J_6V.1, J_6V.2, J_ALERT.1, J_BATT.2, J_ESC1.2, J_ESC2.2, J_ESC3.2, J_ESC4.2, J_I2C.1, R_CHGND.1, R_DSG_G.2, R_FB1_2.2, R_FB2_2.2, R_FB6_2.2, U_BEC_5V_1.7, U_BEC_5V_1.8, U_BEC_5V_1.9, U_BEC_5V_1.10, U_BEC_5V_1.21, U_BEC_5V_2.7, U_BEC_5V_2.8, U_BEC_5V_2.9, U_BEC_5V_2.10, U_BEC_5V_2.21, U_IS1.3, U_IS2.3, U_IS3.3, U_IS4.3, U_IS_MAIN.3
VBAT: F_ESC1.1, F_ESC2.1, F_ESC3.1, F_ESC4.1, Q_BATT_DSG.1, Q_BATT_DSG.2, Q_BATT_DSG.3, Q_BATT_DSG.4, RS_MAIN.1, RS_MAIN.4, U_IS_MAIN.10
VDIS: C1.1, C2.1, C3.1, CM1.1, CM1.2, CM2.1, CM2.2, C_DM1.1, C_Y1.1, D1.2, F1.1, F1.2, FB_5V1.1, FB_5V2.1, FB_6V.1, J_BATT.1, Q_BATT_DSG.5, Q_BATT_DSG.6, Q_BATT_DSG.7

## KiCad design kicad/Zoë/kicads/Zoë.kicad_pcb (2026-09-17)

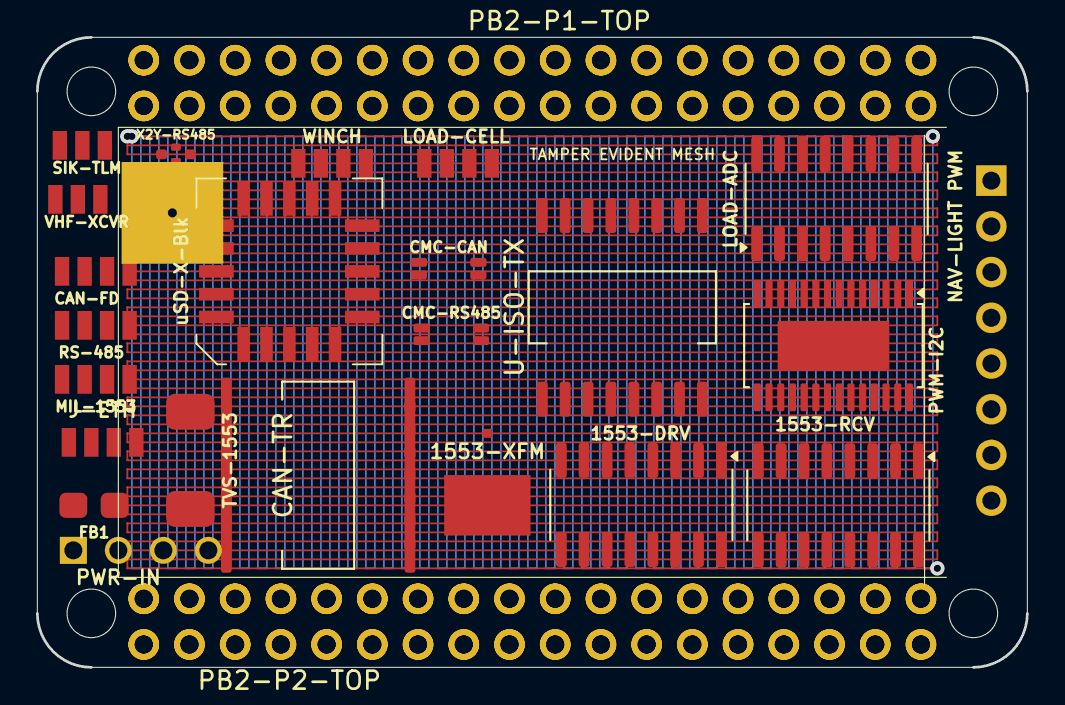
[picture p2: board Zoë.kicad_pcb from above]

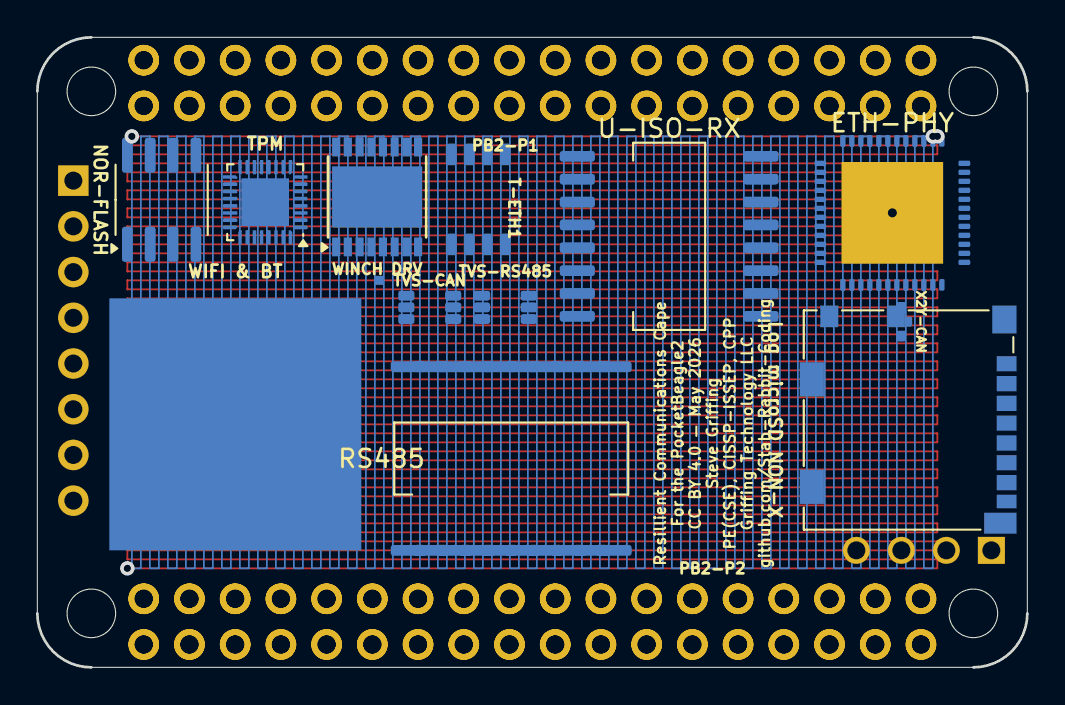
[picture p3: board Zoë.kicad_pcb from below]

Board: 4 copper layers, 55.0 x 35.0 mm, 39 parts (14 on the bottom side), 85 nets.

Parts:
1553-DRV: DS26LV31; SOIC-16_3.9x9.9mm_P1.27mm
1553-RCV: DS26LV32; SOIC-16_3.9x9.9mm_P1.27mm
1553-XFM: SM-1553-11; Package
CAN-FD: JST-GH-4P-CAN; JST_GH_4P
CAN-TR: ISOW1044BDFMR; SOIC-16W_7.5x10.3mm_P1.27mm
CMC-CAN: SRF2012-100Y; Bourns_SRF2012_4T
CMC-RS485: SRF2012-100Y; Bourns_SRF2012_4T
ETH-PHY: ADIN1300BCPZ; QFN-48-1EP_7x7mm_P0.5mm_EP5.65x5.65mm
FB1: 742792512; C_0805_2012Metric
J-ETH: JST-GH-4P-ETH; JST_GH_4P
LOAD-ADC: HX711; SOIC-16_3.9x9.9mm_P1.27mm
LOAD-CELL: JST-GH-4P-LOAD-CELL; JST_GH_4P
Log microSD NON-X: microSD-Log; microSD_HC_Molex_104031-0811
MIL-1553: JST-GH-4P-1553; JST_GH_4P
NAV-LIGHT PWM: 1x8-NavLight-PWM; Connector_PinHeader_2.54mm
NOR-FLASH: W25Q128JV; SOIC-8_3.9x4.9mm_P1.27mm
PB2-P1, PB2-P1-TOP: PB2I-P1-2x18; 2x18_P1_Socket
PB2-P2, PB2-P2-TOP: PB2I-P2-2x18; 2x18_P2_Socket
PWM-I2C: PCA9685; HTSSOP-28-1EP_4.4x9.7mm_P0.65mm_EP2.75x6.2mm
PWR-IN: Nano-Fit-4P-POWER; Connector_Molex_NanoFit
RS485: ADM2795EBRWZ; SOIC-20W_7.5x12.8mm_P1.27mm
RS-485: JST-GH-4P-RS485; JST_GH_4P
SIK-TLM: JST-GH-3P-SiK; JST_GH_3P
T-ETH1: 749010012A; ETH_XFMR_8P_5x3.5mm
TPM: SLB9670; QFN-32-1EP_4x4mm_P0.4mm_EP2.65x2.65mm
TVS-1553: SMAJ33CA; DO-214AC_SMA
TVS-CAN: PRTR5V0U2X; SOT-363_SC-88
TVS-RS485: PRTR5V0U2X; SOT-363_SC-88
U-ISO-RX: ISO7642FDWRR; SOIC-16W_7.5x10.3mm_P1.27mm
U-ISO-TX: ISO7642FDWRR; SOIC-16W_7.5x10.3mm_P1.27mm
VHF-XCVR: JST-GH-3P-RCRS; JST_GH_3P
WIFI & BT: WL1837MOD; RF_Module
WINCH: JST-GH-4P-WINCH; JST_GH_4P
WINCH DRV: DRV8833; HTSSOP-16-1EP_4.4x5mm_P0.65mm_EP3.4x5mm
X2Y-CAN, X2Y-RS485: 4.7nF X2Y; X2Y_Cap_4T_0402
uSD-X-Blk: ATF16V8BQL; PLCC-20

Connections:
+3V3: CAN-TR.1, PB2-P1.33, PB2-P1.34, PB2-P1-TOP.33, PB2-P1-TOP.34, RS485.1, U-ISO-RX.16, U-ISO-TX.1
+5V: FB1.1, FB1.2, PB2-P1.35, PB2-P1-TOP.35, PB2-P2.35, PB2-P2-TOP.35
CAN_H: CAN-TR.9, CMC-CAN.1, CMC-CAN.3, TVS-CAN.1
CAN_L: CAN-TR.10, CMC-CAN.2, CMC-CAN.4, TVS-CAN.3
CAN_STB: CAN-TR.3, PB2-P1.12, PB2-P1-TOP.12
ETH_LINE_RXN: J-ETH.4, T-ETH1.8
ETH_LINE_RXP: J-ETH.3, T-ETH1.7
ETH_LINE_TXN: J-ETH.2, T-ETH1.6
ETH_LINE_TXP: J-ETH.1, T-ETH1.5
ETH_RXN: ETH-PHY.5, T-ETH1.4
ETH_RXP: ETH-PHY.4, T-ETH1.3
ETH_TXN: ETH-PHY.2, T-ETH1.2
ETH_TXP: ETH-PHY.1, T-ETH1.1
GND: CAN-TR.8, ETH-PHY.3, ETH-PHY.6, ETH-PHY.10, ETH-PHY.11, ETH-PHY.12, ETH-PHY.49, PB2-P1.1, PB2-P1.2, PB2-P1.36, PB2-P1-TOP.1, PB2-P1-TOP.2, PB2-P1-TOP.36, PB2-P2.36, PB2-P2-TOP.36, RS485.2, RS485.7, RS485.8, TVS-1553.1, U-ISO-RX.9, U-ISO-TX.8, X2Y-CAN.1, X2Y-CAN.2, X2Y-CAN.3, X2Y-RS485.1, X2Y-RS485.2, X2Y-RS485.3
GND2_CAN: CAN-TR.12, CAN-TR.13, TVS-CAN.2, X2Y-CAN.4
GND2_ETH: ETH-PHY.21, ETH-PHY.22, ETH-PHY.25, ETH-PHY.34, ETH-PHY.36, U-ISO-RX.8, U-ISO-TX.9
GND2_RS485: RS485.12, RS485.13, RS485.18, RS485.19, TVS-RS485.2, X2Y-RS485.4
I2C0_SCL: PB2-P1.4, PB2-P1-TOP.4, PWM-I2C.24
I2C0_SDA: PB2-P1.3, PB2-P1-TOP.3, PWM-I2C.22
LOAD_CELL_DOUT: PB2-P2.7, PB2-P2-TOP.7
LOAD_CELL_SCK: LOAD-ADC.16, PB2-P2.8, PB2-P2-TOP.8
LORA_DIO0: PB2-P1.20, PB2-P1-TOP.20
LORA_RESETN: PB2-P1.19, PB2-P1-TOP.19
MCAN1_RX: CAN-TR.4, PB2-P1.13, PB2-P1-TOP.13
MCAN1_TX: CAN-TR.2, PB2-P1.14, PB2-P1-TOP.14
MDC: ETH-PHY.19, PB2-P2.18, PB2-P2-TOP.18, U-ISO-TX.6, U-ISO-TX.11
MDIO: ETH-PHY.18, PB2-P2.17, PB2-P2-TOP.17, U-ISO-RX.7, U-ISO-RX.10
PHY1_INTRN: ETH-PHY.20, PB2-P2.16, PB2-P2-TOP.16, U-ISO-RX.6, U-ISO-RX.11
PHY1_RSTN: ETH-PHY.35, PB2-P2.15, PB2-P2-TOP.15, U-ISO-TX.7, U-ISO-TX.10
PHY2_INTRN: PB2-P2.14, PB2-P2-TOP.14
PHY2_RSTN: PB2-P2.13, PB2-P2-TOP.13
PRU_1553_RX_N: 1553-RCV.13, PB2-P1.5, PB2-P1-TOP.5
PRU_1553_RX_P: PB2-P1.6, PB2-P1-TOP.6
PRU_1553_TX_N: 1553-DRV.6, PB2-P1.7, PB2-P1-TOP.7
PRU_1553_TX_P: 1553-DRV.10, PB2-P1.8, PB2-P1-TOP.8
PWM_CH0: PB2-P2.6, PB2-P2-TOP.6, uSD-X-Blk.6
PWM_CH1: PB2-P2.5, PB2-P2-TOP.5, PWM-I2C.11, uSD-X-Blk.5
PWM_CH2: PB2-P2.4, PB2-P2-TOP.4, PWM-I2C.10, uSD-X-Blk.4
PWM_CH3: PB2-P2.3, PB2-P2-TOP.3, PWM-I2C.9, uSD-X-Blk.3
RMII0_CRS_DV: ETH-PHY.32, PB2-P2.29, PB2-P2-TOP.29, U-ISO-RX.4, U-ISO-RX.13
RMII0_REF_CLK: ETH-PHY.29, PB2-P2.27, PB2-P2-TOP.27, U-ISO-TX.2, U-ISO-TX.15
RMII0_RXD0: ETH-PHY.30, PB2-P2.31, PB2-P2-TOP.31, U-ISO-RX.2, U-ISO-RX.15
RMII0_RXD1: ETH-PHY.31, PB2-P2.30, PB2-P2-TOP.30, U-ISO-RX.3, U-ISO-RX.14
RMII0_RX_ER: ETH-PHY.33, PB2-P2.28, PB2-P2-TOP.28, U-ISO-RX.5, U-ISO-RX.12
RMII0_TXD0: ETH-PHY.28, PB2-P2.34, PB2-P2-TOP.34, U-ISO-TX.3, U-ISO-TX.14
RMII0_TXD1: ETH-PHY.27, PB2-P2.33, PB2-P2-TOP.33, U-ISO-TX.4, U-ISO-TX.13
RMII0_TX_EN: ETH-PHY.26, PB2-P2.32, PB2-P2-TOP.32, U-ISO-TX.5, U-ISO-TX.12
RMII1_CRS_DV: PB2-P2.21, PB2-P2-TOP.21
RMII1_REF_CLK: PB2-P2.19, PB2-P2-TOP.19
RMII1_RXD0: PB2-P2.23, PB2-P2-TOP.23
RMII1_RXD1: PB2-P2.22, PB2-P2-TOP.22
RMII1_RX_ER: PB2-P2.20, PB2-P2-TOP.20
RMII1_TXD0: PB2-P2.26, PB2-P2-TOP.26
RMII1_TXD1: PB2-P2.25, PB2-P2-TOP.25
RMII1_TX_EN: PB2-P2.24, PB2-P2-TOP.24
RS485_A: CMC-RS485.1, CMC-RS485.3, RS485.14, TVS-RS485.1
RS485_B: CMC-RS485.2, CMC-RS485.4, RS485.15, TVS-RS485.3
RS485_DE: PB2-P1.9, PB2-P1-TOP.9, RS485.4, RS485.5
RS485_RX: PB2-P1.10, PB2-P1-TOP.10, RS485.6
RS485_TX: PB2-P1.11, PB2-P1-TOP.11, RS485.3
SDIO_CLK: Log microSD NON-X.6, PB2-P1.32, PB2-P1-TOP.32
SDIO_CMD: Log microSD NON-X.8, PB2-P1.31, PB2-P1-TOP.31
SDIO_D0: Log microSD NON-X.4, PB2-P1.30, PB2-P1-TOP.30
SDIO_D1: PB2-P1.29, PB2-P1-TOP.29
SDIO_D2: Log microSD NON-X.3, PB2-P1.28, PB2-P1-TOP.28
SDIO_D3: PB2-P1.27, PB2-P1-TOP.27
SERVO6: PB2-P2.2, PB2-P2-TOP.2
SERVO7: PB2-P2.1, PB2-P2-TOP.1, uSD-X-Blk.15
SPI1_CLK: NOR-FLASH.2, PB2-P1.25, PB2-P1-TOP.25, TPM.23
SPI1_CS_LORA: PB2-P1.26, PB2-P1-TOP.26
SPI1_CS_NOR: NOR-FLASH.3, PB2-P1.22, PB2-P1-TOP.22
SPI1_CS_TPM: PB2-P1.21, PB2-P1-TOP.21, TPM.28
SPI1_MISO: NOR-FLASH.6, PB2-P1.23, PB2-P1-TOP.23, TPM.22
SPI1_MOSI: NOR-FLASH.5, PB2-P1.24, PB2-P1-TOP.24, TPM.21
TPM_IRQN: PB2-P2.12, PB2-P2-TOP.12, TPM.24
TPM_RSTN: PB2-P2.11, PB2-P2-TOP.11, TPM.1
UART_RCRS_RX: PB2-P1.15, PB2-P1-TOP.15
UART_RCRS_TX: PB2-P1.16, PB2-P1-TOP.16
UART_SIK_RX: PB2-P1.17, PB2-P1-TOP.17
UART_SIK_TX: PB2-P1.18, PB2-P1-TOP.18
VCC2_CAN: CAN-TR.14, TVS-CAN.5
VCC2_ETH: ETH-PHY.7, ETH-PHY.8, ETH-PHY.9, ETH-PHY.40, ETH-PHY.41, U-ISO-RX.1, U-ISO-TX.16
VCC2_RS485: RS485.11, RS485.20, TVS-RS485.5
WINCH_IN1: PB2-P2.10, PB2-P2-TOP.10, WINCH DRV.5
WINCH_IN2: PB2-P2.9, PB2-P2-TOP.9, WINCH DRV.8

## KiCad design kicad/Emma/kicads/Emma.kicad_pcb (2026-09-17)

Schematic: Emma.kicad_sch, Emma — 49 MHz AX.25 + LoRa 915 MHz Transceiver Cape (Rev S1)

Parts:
1.2k C: 10nF RX RC Bandpass 1200Hz Cap
1.2k R: 13k Ohm RX RC Bandpass 1200Hz
2.2k C: 10nF RX RC Bandpass 2200Hz Cap
2.2k R: 7.2k Ohm RX RC Bandpass 2200Hz
49M DDS: Si5351A-B-GT 49MHz DDS I2C Synthesiser
+3V 10n: 10nF C0G 0402 +3V3 VHF 49MHz Bypass
+3V 10u: 10uF X5R 0805 +3V3 Mid-freq
+3V 100n: 100nF X7R 0402 +3V3 HF Bypass
+3V 100u: 100uF 10V X5R 1210 +3V3 Bulk
+5V 100n: 100nF X7R 0402 +5V HF Bypass
+5V 100u: 100uF 10V X5R 1210 +5V Bulk
+5V Bead: 742792512
AFSK Cp: 1uF AFSK Audio Coupling DAC→PA
ANT CMC: SRF2012-100Y
ANT RPSMA: RPSMA-EDGE-50R
ANT TVS: PRTR5V0U2X
C1 120p: 120pF C0G LPF Shunt-1
C2 180p: 180pF C0G LPF Shunt-2
C3 120p: 120pF C0G LPF Shunt-3
CMP By: 100nF +3V3 U2B CMP Bypass
C_INV: 100nF C0G 0402 INV1 VCC Bypass
C_MUX: 100nF C0G 0402 MUX1 VCC Bypass
DAC By: 100nF +3V3 U2A DAC Bypass
ETH-PHY: ADIN1300BCPZ
GND X2Y: 4.7nF_X2Y_C0G
INV1: SN74LVC1G04 SOT-23-5 3.3V UART_RX_F->SBUS_OUT
J-ETH: JST-GH-4P-ETH
L1 100n: 100nH Coilcraft-0805HQ-101J LPF Series-1
L2 180n: 180nH Coilcraft-0805HQ-181J LPF Series-2
L3 180n: 180nH Coilcraft-0805HQ-181J LPF Series-3
LDO 3V3: MCP1703T-3302 LDO 3.3V 72dB-PSRR@100kHz
LDO By: 100nF +3V3 U6 LDO Bypass
LNA: MGA-82563 LNA 2.4dB NF 50-6000MHz
LNA By: 100nF +3V3 U4 LNA Bypass
LoRa: RFM95W
MUX1: SN74LVC1G157 SC-70-6 2:1MUX UART/SBUS Select
OSC By: 100nF +3V3 X1 TCXO Bypass
PA 100mW: 2N3866 NPN BJT PA Class-AB Final 100mW
PA By: 100nF +5V U3 PA VCC Bypass
PA By2: 1nF U3B Collector RF Bypass
PA Cb1: 100pF DDS-RF Coupling Cap to U3A
PA Cb2: 100pF PA Interstage Bypass
PA Drvr: MMBT2222A NPN BJT PA Class-A Driver
PA Rb1: 10k Ohm U3A Base Bias Resistor
PA Rb2: 1k Ohm U3B Base Bias Resistor
PA Rc1: 100 Ohm U3A Collector Load
PA Re: 10 Ohm U3B Emitter Degeneration
PB2-P1: PB2I-P1-2x18
PB2-P2: PB2I-P2-2x18
PGND 10n: 10nF C0G 0402 GND-PGND Moat Bridge
PTT Bead: 742792510 0402 Ferrite Bead 600Ohm@100MHz
RSSI Hi: 10k Ohm RSSI Scale Upper
RSSI Lo: 10k Ohm RSSI Scale Lower
RSSI_CBY: 100nF RSSI_CMP VCC Bypass
RSSI_CMP: LMV331 RSSI Carrier-Detect Comparator
RSSI_RH: 100k RSSI DCD Threshold Upper
RSSI_RL: 100k RSSI DCD Threshold Lower
RX Bead: 742792510 0402 Ferrite Bead 600Ohm@100MHz
RX Demod: LM393 Comparator RX-AFSK Demodulator
R_MODE: 10k Ohm MODE_SEL Pull-Down UART=default
S1: SPST-SMD OPEN=UART CLOSED=SBUS
SMA ESD: SMAJ5.0A Bidirectional TVS 5V Antenna ESD
SW By: 100nF +3V3 U5 Switch Bypass
T-ETH: 749010012A
T/R Sw: PE4259-63 SPDT TX/RX Switch ≥35dB isolation
TCXO 25M: TG2520SMN 25MHz TCXO ±0.5ppm
TX Bead: 742792510 0402 Ferrite Bead 600Ohm@100MHz
TX DAC: MCP4921 12-bit SPI DAC TX-AFSK Audio
Th Hi: 10k Ohm LM393 Threshold Upper
Th Lo: 10k Ohm LM393 Threshold Lower
U1 ByA: 100nF +3V3 U1-VDDA Bypass
U1 ByB: 100nF +3V3 U1-VDD Bypass
UART CMC: SRF2012-100Y CMC UART TX/RX Pair 10uH
UART TVS: PRTR5V0U2X Dual TVS 5.5V UART-TX/RX ESD

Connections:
+3V3: 49M DDS.1 (+3V3), 49M DDS.10 (+3V3), +3V 10n.1 (+3V3), +3V 10u.1 (+3V3), +3V 100n.1 (+3V3), +3V 100u.1 (+3V3), CMP By.1 (+3V3), C_INV.1 (+3V3), C_MUX.1 (+3V3), DAC By.1 (+3V3), INV1.4 (+3V3), LDO 3V3.3 (+3V3), LDO 3V3.4 (+3V3), LDO By.1 (+3V3), LNA.4 (+3V3), LNA By.1 (+3V3), MUX1.4 (+3V3), OSC By.1 (+3V3), PB2-P1.33 (+3V3), PB2-P1.34 (+3V3), RSSI_CBY.1 (+3V3), RSSI_CMP.2 (+3V3), RSSI_RH.1 (+3V3), RX Demod.2 (+3V3), S1.1 (+3V3), SW By.1 (+3V3), TCXO 25M.1 (+3V3), TCXO 25M.4 (+3V3), TX DAC.1 (+3V3), TX DAC.6 (+3V3), Th Hi.1 (+3V3), U1 ByA.1 (+3V3), U1 ByB.1 (+3V3)
+5V: +5V Bead.1 (+5V), PB2-P1.35 (+5V), PB2-P2.35 (+5V)
+5V_FILT: +5V 100n.1 (+5V_FILT), +5V 100u.1 (+5V_FILT), +5V Bead.2 (+5V_FILT), LDO 3V3.1 (+5V_FILT), PA By.1 (+5V_FILT), PA Rb1.1 (+5V_FILT), PA Rc1.1 (+5V_FILT)
AFSK_IN: AFSK Cp.2 (AFSK_IN), RX Demod.1 (AFSK_IN)
AFSK_OUT: AFSK Cp.1 (AFSK_OUT), TX DAC.7 (AFSK_OUT)
ANT: ANT CMC.1, ANT CMC.2, ANT RPSMA.1 (ANT), ANT TVS.2 (ANT), SMA ESD.1 (ANT)
CAN_STB: PB2-P1.12 (CAN_STB)
COMP_IN: 1.2k C.1 (COMP_IN), 1.2k R.2 (COMP_IN), 2.2k C.1 (COMP_IN), 2.2k R.2 (COMP_IN), RX Demod.3 (COMP_IN), Th Lo.1 (COMP_IN)
DDS_CLK: 49M DDS.6 (DDS_CLK), TX DAC.3 (DDS_CLK)
DDS_DAT: 49M DDS.7 (DDS_DAT), TX DAC.4 (DDS_DAT)
DDS_FSYNC: TX DAC.2 (DDS_FSYNC)
DDS_RF: 49M DDS.3 (DDS_RF), PA Cb1.1 (DDS_RF), PA Drvr.1 (DDS_RF), PA Rb1.2 (DDS_RF)
EMMA_ETH_LINE_RXN: J-ETH.4 (EMMA_ETH_LINE_RXN), T-ETH.8 (EMMA_ETH_LINE_RXN)
EMMA_ETH_LINE_RXP: J-ETH.3 (EMMA_ETH_LINE_RXP), T-ETH.7 (EMMA_ETH_LINE_RXP)
EMMA_ETH_LINE_TXN: J-ETH.2 (EMMA_ETH_LINE_TXN), T-ETH.6 (EMMA_ETH_LINE_TXN)
EMMA_ETH_LINE_TXP: J-ETH.1 (EMMA_ETH_LINE_TXP), T-ETH.5 (EMMA_ETH_LINE_TXP)
EMMA_ETH_RXN: ETH-PHY.5 (EMMA_ETH_RXN), T-ETH.4 (EMMA_ETH_RXN)
EMMA_ETH_RXP: ETH-PHY.4 (EMMA_ETH_RXP), T-ETH.3 (EMMA_ETH_RXP)
EMMA_ETH_TXN: ETH-PHY.2 (EMMA_ETH_TXN), T-ETH.2 (EMMA_ETH_TXN)
EMMA_ETH_TXP: ETH-PHY.1 (EMMA_ETH_TXP), T-ETH.1 (EMMA_ETH_TXP)
GND: 1.2k C.2 (GND), 2.2k C.2 (GND), 49M DDS.2 (GND), 49M DDS.4 (GND), 49M DDS.5 (GND), 49M DDS.9 (GND), +3V 10n.2 (GND), +3V 10u.2 (GND), +3V 100n.2 (GND), +3V 100u.2 (GND), +5V 100n.2 (GND), +5V 100u.2 (GND), ANT RPSMA.2 (GND), ANT RPSMA.3 (GND), ANT TVS.1 (GND), ANT TVS.3 (GND), ANT TVS.4 (GND), ANT TVS.6 (GND), C1 120p.2 (GND), C2 180p.2 (GND), C3 120p.2 (GND), CMP By.2 (GND), C_INV.2 (GND), C_MUX.2 (GND), DAC By.2 (GND), ETH-PHY.3 (GND), ETH-PHY.6 (GND), ETH-PHY.10 (GND), ETH-PHY.11 (GND), ETH-PHY.12 (GND), ETH-PHY.49 (GND), GND X2Y.1, GND X2Y.2, INV1.2 (GND), LDO 3V3.2 (GND), LDO 3V3.5 (GND), LDO By.2 (GND), LNA.5 (GND), LNA.6 (GND), LNA By.2 (GND), LoRa.1 (GND), LoRa.8 (GND), LoRa.10 (GND), MUX1.2 (GND), OSC By.2 (GND), PA 100mW.2 (GND), PA By.2 (GND), PA By2.2 (GND), PA Cb2.2 (GND), PA Drvr.2 (GND), PA Re.2 (GND), PB2-P1.1 (GND), PB2-P1.2 (GND), PB2-P1.36 (GND), PB2-P2.36 (GND), PGND 10n.1, PGND 10n.2, RSSI Lo.2 (GND), RSSI_CBY.2 (GND), RSSI_CMP.4 (GND), RSSI_RL.2 (GND), RX Demod.4 (GND), RX Demod.5 (GND), R_MODE.2 (GND), SMA ESD.2 (GND), SW By.2 (GND), T/R Sw.2 (GND), T/R Sw.6 (GND), TCXO 25M.2 (GND), TX DAC.5 (GND), TX DAC.8 (GND), Th Hi.2 (GND), Th Lo.2 (GND), U1 ByA.2 (GND), U1 ByB.2 (GND), UART TVS.1 (GND), UART TVS.3 (GND), UART TVS.4 (GND), UART TVS.6 (GND)
GND2_ETH: ETH-PHY.21 (GND2_ETH), ETH-PHY.22 (GND2_ETH), ETH-PHY.25 (GND2_ETH), ETH-PHY.34 (GND2_ETH), ETH-PHY.36 (GND2_ETH)
I2C0_SCL: PB2-P1.4 (I2C0_SCL)
I2C0_SDA: PB2-P1.3 (I2C0_SDA)
LOAD_CELL_DOUT: PB2-P2.7 (LOAD_CELL_DOUT)
LOAD_CELL_SCK: PB2-P2.8 (LOAD_CELL_SCK)
LORA_DIO0: PB2-P1.20 (LORA_DIO0)
LORA_RESETN: LoRa.6 (LORA_RESETN), PB2-P1.19 (LORA_RESETN)
MCAN1_RX: PB2-P1.13 (MCAN1_RX)
MCAN1_TX: PB2-P1.14 (MCAN1_TX)
MDC: ETH-PHY.19 (MDC), PB2-P2.18 (MDC)
MDIO: ETH-PHY.18 (MDIO), PB2-P2.17 (MDIO)
MODE_SEL: MUX1.5 (MODE_SEL), R_MODE.1 (MODE_SEL), S1.2 (MODE_SEL)
PA_EMIT: PA Re.1 (PA_EMIT)
PA_INT: PA 100mW.1 (PA_INT), PA Cb1.2 (PA_INT), PA Cb2.1 (PA_INT), PA Drvr.3 (PA_INT), PA Rb2.1, PA Rb2.2, PA Rc1.2 (PA_INT)
PHY1_INTRN: PB2-P2.16 (PHY1_INTRN)
PHY1_RSTN: PB2-P2.15 (PHY1_RSTN)
PHY2_INTRN: ETH-PHY.20 (PHY2_INTRN), PB2-P2.14 (PHY2_INTRN)
PHY2_RSTN: ETH-PHY.35 (PHY2_RSTN), PB2-P2.13 (PHY2_RSTN)
PRU_1553_RX_N: PB2-P1.5 (PRU_1553_RX_N)
PRU_1553_RX_P: PB2-P1.6 (PRU_1553_RX_P)
PRU_1553_TX_N: PB2-P1.7 (PRU_1553_TX_N)
PRU_1553_TX_P: PB2-P1.8 (PRU_1553_TX_P)
PTT_N: PB2-P2.1 (PTT_N), PTT Bead.1, PTT Bead.2, T/R Sw.4 (PTT_N)
PWM_CH0: PB2-P2.6 (PWM_CH0)
PWM_CH1: PB2-P2.5 (PWM_CH1)
PWM_CH2: PB2-P2.4 (PWM_CH2)
PWM_CH3: PB2-P2.3 (PWM_CH3)
RF_ANT_SW: T/R Sw.1 (RF_ANT_SW)
RF_FILT: C3 120p.1 (RF_FILT), L3 180n.2 (RF_FILT), T/R Sw.5 (RF_FILT)
RF_LPF_N1: C1 120p.1 (RF_LPF_N1), L1 100n.2 (RF_LPF_N1), L2 180n.1 (RF_LPF_N1)
RF_LPF_N2: C2 180p.1 (RF_LPF_N2), L2 180n.2 (RF_LPF_N2), L3 180n.1 (RF_LPF_N2)
RF_RX: LNA.3 (RF_RX), T/R Sw.3 (RF_RX)
RF_TX: ANT TVS.5 (RF_TX), L1 100n.1 (RF_TX), PA 100mW.3 (RF_TX), PA By2.1 (RF_TX)
RMII0_CRS_DV: PB2-P2.29 (RMII0_CRS_DV)
RMII0_REF_CLK: PB2-P2.27 (RMII0_REF_CLK)
RMII0_RXD0: PB2-P2.31 (RMII0_RXD0)
RMII0_RXD1: PB2-P2.30 (RMII0_RXD1)
RMII0_RX_ER: PB2-P2.28 (RMII0_RX_ER)
RMII0_TXD0: PB2-P2.34 (RMII0_TXD0)
RMII0_TXD1: PB2-P2.33 (RMII0_TXD1)
RMII0_TX_EN: PB2-P2.32 (RMII0_TX_EN)
RMII1_CRS_DV: ETH-PHY.32 (RMII1_CRS_DV), PB2-P2.21 (RMII1_CRS_DV)
RMII1_REF_CLK: ETH-PHY.29 (RMII1_REF_CLK), PB2-P2.19 (RMII1_REF_CLK)
RMII1_RXD0: ETH-PHY.30 (RMII1_RXD0), PB2-P2.23 (RMII1_RXD0)
RMII1_RXD1: ETH-PHY.31 (RMII1_RXD1), PB2-P2.22 (RMII1_RXD1)
RMII1_RX_ER: ETH-PHY.33 (RMII1_RX_ER), PB2-P2.20 (RMII1_RX_ER)
RMII1_TXD0: ETH-PHY.28 (RMII1_TXD0), PB2-P2.26 (RMII1_TXD0)
RMII1_TXD1: ETH-PHY.27 (RMII1_TXD1), PB2-P2.25 (RMII1_TXD1)
RMII1_TX_EN: ETH-PHY.26 (RMII1_TX_EN), PB2-P2.24 (RMII1_TX_EN)
RS485_DE: PB2-P1.9 (RS485_DE)
RS485_RX: PB2-P1.10 (RS485_RX)
RS485_TX: PB2-P1.11 (RS485_TX)
RSSI_ANA: RSSI Hi.2 (RSSI_ANA), RSSI Lo.1 (RSSI_ANA), RSSI_CMP.1 (RSSI_ANA)
RSSI_DCD: PB2-P2.2 (RSSI_DCD), RSSI_CMP.5 (RSSI_DCD)
RSSI_RAW: LNA.2 (RSSI_RAW), RSSI Hi.1 (RSSI_RAW)
RSSI_REF: RSSI_CMP.3 (RSSI_REF), RSSI_RH.2 (RSSI_REF), RSSI_RL.1 (RSSI_REF)
RX_LNA: 1.2k R.1 (RX_LNA), 2.2k R.1 (RX_LNA), LNA.1 (RX_LNA)
SBUS_OUT: INV1.3 (SBUS_OUT), MUX1.6 (SBUS_OUT)
SDIO_CLK: PB2-P1.32 (SDIO_CLK)
SDIO_CMD: PB2-P1.31 (SDIO_CMD)
SDIO_D0: PB2-P1.30 (SDIO_D0)
SDIO_D1: PB2-P1.29 (SDIO_D1)
SDIO_D2: PB2-P1.28 (SDIO_D2)
SDIO_D3: PB2-P1.27 (SDIO_D3)
SPI1_CLK: LoRa.4 (SPI1_CLK), PB2-P1.25 (SPI1_CLK)
SPI1_CS_LORA: LoRa.5 (SPI1_CS_LORA), PB2-P1.26 (SPI1_CS_LORA)
SPI1_CS_NOR: PB2-P1.22 (SPI1_CS_NOR)
SPI1_CS_TPM: PB2-P1.21 (SPI1_CS_TPM)
SPI1_MISO: LoRa.2 (SPI1_MISO), PB2-P1.23 (SPI1_MISO)
SPI1_MOSI: LoRa.3 (SPI1_MOSI), PB2-P1.24 (SPI1_MOSI)
TCXO_OUT: 49M DDS.8 (TCXO_OUT), TCXO 25M.3 (TCXO_OUT)
TPM_IRQN: PB2-P2.12 (TPM_IRQN)
TPM_RSTN: PB2-P2.11 (TPM_RSTN)
UART_RCRS_RX: PB2-P1.15 (UART_RCRS_RX), UART CMC.1 (UART_RCRS_RX), UART TVS.2 (UART_RCRS_RX)
UART_RCRS_TX: PB2-P1.16 (UART_RCRS_TX), UART CMC.4 (UART_RCRS_TX), UART TVS.5 (UART_RCRS_TX)
UART_RX_F: INV1.1 (UART_RX_F), MUX1.1 (UART_RX_F), RX Bead.1, RX Bead.2
UART_RX_MUX: MUX1.3 (UART_RX_MUX), UART CMC.3 (UART_RX_MUX)
UART_SIK_RX: PB2-P1.17 (UART_SIK_RX)
UART_SIK_TX: PB2-P1.18 (UART_SIK_TX)
UART_TX_F: TX Bead.1, TX Bead.2, UART CMC.2 (UART_TX_F)
VCC2_ETH: ETH-PHY.7 (VCC2_ETH), ETH-PHY.8 (VCC2_ETH), ETH-PHY.9 (VCC2_ETH), ETH-PHY.40 (VCC2_ETH), ETH-PHY.41 (VCC2_ETH)
WINCH_IN1: PB2-P2.10 (WINCH_IN1)
WINCH_IN2: PB2-P2.9 (WINCH_IN2)

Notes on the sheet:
POWER SUPPLY (5V input filter, MCP1703 LDO, bypass cascade)
DDS / TCXO (Si5351A 49 MHz synthesiser)
PA CHAIN (MMBT2222A driver + 2N3866 100 mW final)
6-ELEMENT CHEBYSHEV LPF
T/R SWITCH, LNA, ANTENNA PORT
AFSK MODEM (MCP4921 TX DAC, LM393 RX demod, tone filters)
UART / SBUS DIGITAL (CMC, TVS, beads, inverter, mux)
RSSI CARRIER-DETECT (NEW 2026-07-04 — analog RSSI -> 1-bit RSSI_DCD)
LoRa 915 MHz (RFM95W, SPI via PB2-P1)
ETHERNET 2nd PORT (ADIN1300 PHY + T-ETH isolation xfmr, JST-GH-4P line)
PB2-I PASSTHROUGH RAILS (PocketBeagle 2 Industrial P1 + P2)

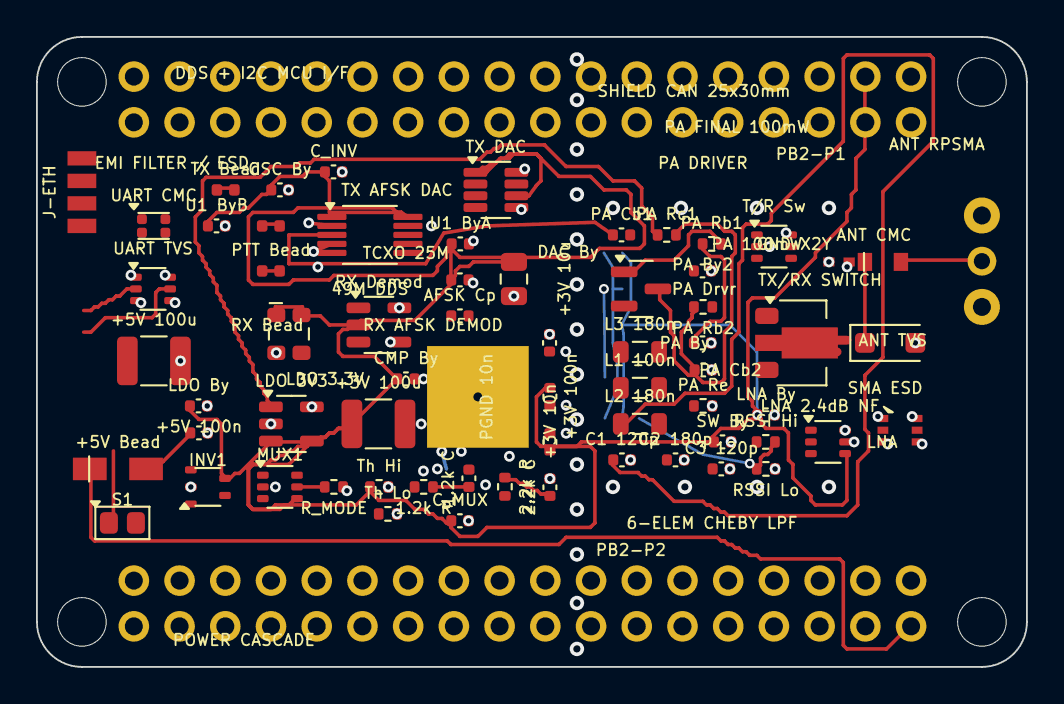
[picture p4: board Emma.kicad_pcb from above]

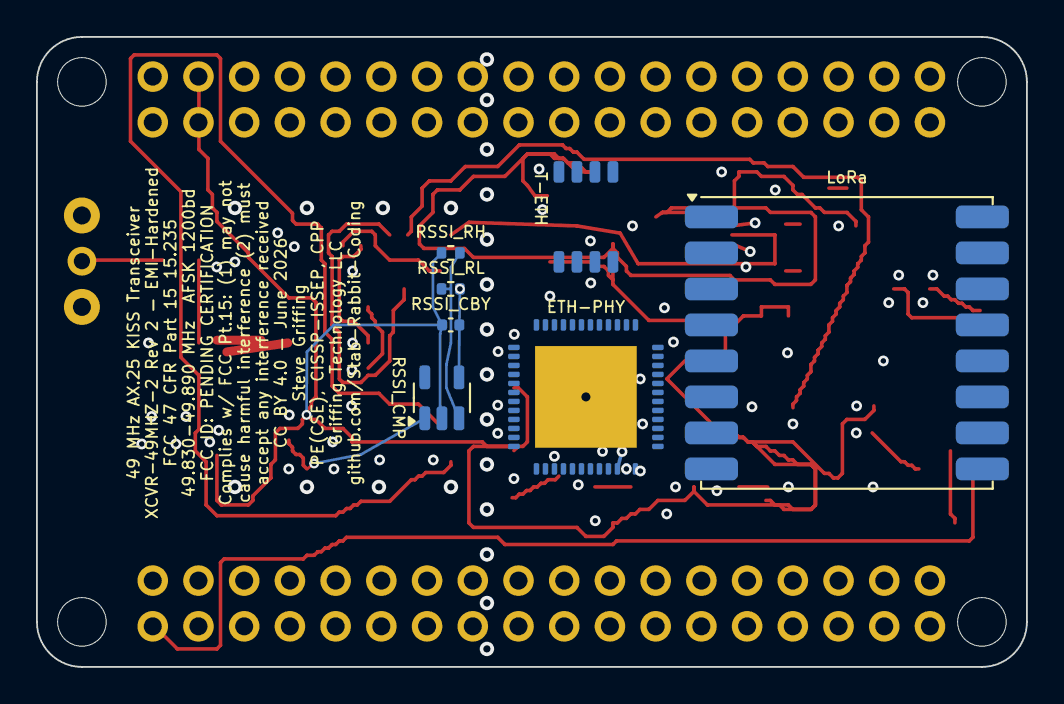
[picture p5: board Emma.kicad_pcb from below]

Board: 4 copper layers, 55.0 x 35.0 mm, 74 parts (7 on the bottom side), 58 nets.

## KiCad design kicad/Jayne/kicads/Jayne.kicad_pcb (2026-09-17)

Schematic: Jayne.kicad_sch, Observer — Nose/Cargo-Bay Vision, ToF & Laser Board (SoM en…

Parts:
CMC5: SRF2012-100Y (CAN); L_CommonModeChoke_Coilcraft_0805USB
C_2V5I, C_2V5O: 1uF; C_0402_1005Metric
C_ISO: 100nF/500V; C_0402_1005Metric
C_VCORE: 1uF; C_0402_1005Metric
C_VISO: 1uF; C_0402_1005Metric
D5: PRTR5V0U2X (CAN); SOT-363_SC-70-6
J_CAM1: CSI CLK/D0; JST_GH_BM04B-GHS-TBT_1x04-1MP_P1.25mm_Vertical
J_CAM2: CAM SDA/SCL/RST/3V3; JST_GH_BM04B-GHS-TBT_1x04-1MP_P1.25mm_Vertical
J_CAM_DS: Direct-solder camera land (nose; DNP if J_CAM* us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; DS_Camera_9P
J_CANFD: 5V/CANH/CANL/GND; JST_GH_BM04B-GHS-TBT_1x04-1MP_P1.25mm_Vertical
J_CHASSIS_R: 0R; R_0402_1005Metric
J_ETH_IN: JST-GH 5P shielded Eth ring; JST_GH_SM05B-GHS-TB_1x05-1MP_P1.25mm_Horizontal
J_ETH_OUT: JST-GH 5P shielded Eth ring; JST_GH_SM05B-GHS-TB_1x05-1MP_P1.25mm_Horizontal
J_LASER: laser +5V/cathode; JST_SH_BM02B-SRSS-TB_1x02-1MP_P1.00mm_Vertical
J_LASER_DS: Direct-solder laser land (nose; DNP if J_LASER us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; DS_Laser_2P
J_PWR: JST-GH 2P +5V/GND; JST_GH_BM02B-GHS-TBT_1x02-1MP_P1.25mm_Vertical
J_SWD: SWD: DIO/CLK/NRST/GND; JST_GH_BM04B-GHS-TBT_1x04-1MP_P1.25mm_Vertical
J_TOF: TFmini-S 5V/GND/TX/RX; JST_GH_BM04B-GHS-TBT_1x04-1MP_P1.25mm_Vertical
J_TOF_DS: Direct-solder ToF land (nose; DNP if J_TOF used); DS_ToF_4P
Q1: AO3400 logic-level N-MOSFET; SOT-23
R1: 100R gate; R_0402_1005Metric
R2: 10k pulldown; R_0402_1005Metric
R_FB1B, R_FB3B: R_fbbot; R_0402_1005Metric
R_FB1T, R_FB3T: R_fbtop; R_0402_1005Metric
R_ISET: 6.04k; R_0402_1005Metric
R_NRST: 10k; R_0402_1005Metric
R_PG1, R_PG3: 100k; R_0402_1005Metric
R_PORZ: 10k; R_0402_1005Metric
R_REXT: 191R; R_0402_1005Metric
R_SHIELD: 0R; R_0402_1005Metric
T1, T2: Wurth 749010012A; Wurth_749010012A_10-100BASE-TX
T1_CMC1, T1_CMC2, T2_CMC1, T2_CMC2: SRF2012-100Y; L_CommonModeChoke_Coilcraft_0805USB
T1_D1, T1_D2, T2_D1, T2_D2: PRTR5V0U2X; SOT-363_SC-70-6
U2: Microchip KSZ9477; TQFP-128-1EP_KSZ9477_14x14mm_P0.4mm_EP10x10
U3: TI MSPM0G3507; QFN-48-1EP_7x7mm_P0.5mm_EP5.15x5.15mm
U4: TI ISOW1044BDFMR; SOIC-20W_7.5x12.8mm_P1.27mm
U5: Infineon SLB9670; QFN-32-1EP_5x5mm_P0.5mm_EP3.45x3.45mm
U_REG_1V2: TLV62569 -> +1V2; SOT-23-6
U_REG_1V2_CI, U_REG_3V3_CI: 10uF; C_0402_1005Metric
U_REG_1V2_CO, U_REG_3V3_CO: 22uF; C_0402_1005Metric
U_REG_1V2_L, U_REG_3V3_L: 2.2uH; L_Taiyo-Yuden_NR-20xx
U_REG_2V5: TLV75725 -> +2V5; SOT-23-5
U_REG_3V3: TLV62569 -> +3V3; SOT-23-6
U_SOM: phyCORE-AM62x PCM-071; phyCORE-AM62x_PCM071_2xBTH-060
Y1: 25MHz; Crystal_SMD_2012-2Pin_2.0x1.2mm

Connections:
+1V2: R_FB1T.1, R_PG1.1, U2.3 (AVDDL), U2.11 (DVDDL), U2.14 (AVDDL), U2.19 (AVDDL), U2.23 (DVDDL), U2.30 (AVDDL), U2.36 (AVDDL), U2.41 (AVDDL), U2.45 (DVDDL), U2.56 (DVDDL), U2.66 (DVDDL), U2.70 (DVDDL), U2.71 (VDDLS), U2.84 (VDDLS), U2.87 (DVDDL), U2.104 (DVDDL), U2.110 (DVDDL), U2.114 (AVDDL), U2.119 (AVDDL), U2.124 (AVDDL), U_REG_1V2_CO.1, U_REG_1V2_L.2
+1V2_PG: R_PG1.2, U_REG_1V2.6 (PG)
+2V5: C_2V5O.1, U2.10 (AVDDH), U2.22 (AVDDH), U2.33 (AVDDH), U2.44 (AVDDH), U2.72 (VDDHS), U2.83 (VDDHS), U2.111 (AVDDH), U2.122 (AVDDH), U2.128 (AVDDH), U_REG_2V5.5 (OUT)
+3V3: C_2V5I.1, J_CAM2.4, J_CAM_DS.8, R_FB3T.1, R_NRST.1, R_PG3.1, R_PORZ.1, U2.61 (VDDIO), U2.68 (VDDIO), U2.99 (VDDIO), U3.6 (VDD), U4.1 (VIO), U5.7 (PP), U5.8 (VDD), U5.22 (VDD), U_REG_2V5.1 (IN), U_REG_2V5.3 (EN), U_REG_3V3_CO.1, U_REG_3V3_L.2, U_SOM.B1 (SoC_VDDSHV5_SDIO), U_SOM.B2 (VBAT)
+3V3_PG: R_PG3.2, U_REG_3V3.6 (PG)
+5V: J_CANFD.1, J_LASER.1, J_LASER_DS.1, J_PWR.2, J_TOF.1, J_TOF_DS.1, U4.9 (VDD), U_REG_1V2.1 (EN), U_REG_1V2.4 (VIN), U_REG_1V2_CI.1, U_REG_3V3.1 (EN), U_REG_3V3.4 (VIN), U_REG_3V3_CI.1, U_SOM.A1 (VIN), U_SOM.A2 (VIN), U_SOM.A3 (VIN)
CAM_RESET_N: J_CAM2.3, J_CAM_DS.7, U_SOM.A56 (X_WKUP_UART0_CTSN)
CAM_SCL: J_CAM2.2, J_CAM_DS.6, U_SOM.C32 (X_I2C1_SCL)
CAM_SDA: J_CAM2.1, J_CAM_DS.5, U_SOM.C33 (X_I2C1_SDA)
CANFD_H: CMC5.2 (L1B), D5.1 (A1), J_CANFD.2
CANFD_ISOGND: C_VISO.2, U4.11 (GND2), U4.15 (GISOIN), U4.16 (GISOIN), U4.17 (GISOIN)
CANFD_ISO_H: CMC5.1 (L1A), U4.19 (CANH)
CANFD_ISO_L: CMC5.3 (L2A), U4.18 (CANL)
CANFD_L: CMC5.4 (L2B), D5.2 (A2), J_CANFD.3
CANFD_RX: U3.28 (PA13), U4.5 (RXD)
CANFD_TX: U3.27 (PA12), U4.3 (TXD)
CANFD_VISO: C_VISO.1, U4.12 (VISOOUT), U4.13 (VSIN), U4.20 (VISOIN)
CSI_CLK_N: J_CAM1.2, J_CAM_DS.2, U_SOM.B32 (X_CSI0_RXCLKN)
CSI_CLK_P: J_CAM1.1, J_CAM_DS.1, U_SOM.B31 (X_CSI0_RXCLKP)
CSI_D0_N: J_CAM1.4, J_CAM_DS.4, U_SOM.A36 (X_CSI0_RXN0)
CSI_D0_P: J_CAM1.3, J_CAM_DS.3, U_SOM.A35 (X_CSI0_RXP0)
ETH_IN_KSZ_RXN: T1.4 (PHY_RXN), U2.5 (TXRX1M_B)
ETH_IN_KSZ_RXP: T1.3 (PHY_RXP), U2.4 (TXRX1P_B)
ETH_IN_KSZ_TXN: T1.2 (PHY_TXN), U2.2 (TXRX1M_A)
ETH_IN_KSZ_TXP: T1.1 (PHY_TXP), U2.1 (TXRX1P_A)
ETH_IN_LRXN: T1.8 (LINE_RXN), T1_CMC2.3 (L2A)
ETH_IN_LRXP: T1.7 (LINE_RXP), T1_CMC2.1 (L1A)
ETH_IN_LTXN: T1.6 (LINE_TXN), T1_CMC1.3 (L2A)
ETH_IN_LTXP: T1.5 (LINE_TXP), T1_CMC1.1 (L1A)
ETH_IN_RXN: J_ETH_IN.5, T1_CMC2.4 (L2B), T1_D2.2 (A2)
ETH_IN_RXP: J_ETH_IN.4, T1_CMC2.2 (L1B), T1_D2.1 (A1)
ETH_IN_TXN: J_ETH_IN.3, T1_CMC1.4 (L2B), T1_D1.2 (A2)
ETH_IN_TXP: J_ETH_IN.2, T1_CMC1.2 (L1B), T1_D1.1 (A1)
ETH_OUT_KSZ_RXN: T2.4 (PHY_RXN), U2.16 (TXRX2M_B)
ETH_OUT_KSZ_RXP: T2.3 (PHY_RXP), U2.15 (TXRX2P_B)
ETH_OUT_KSZ_TXN: T2.2 (PHY_TXN), U2.13 (TXRX2M_A)
ETH_OUT_KSZ_TXP: T2.1 (PHY_TXP), U2.12 (TXRX2P_A)
ETH_OUT_LRXN: T2.8 (LINE_RXN), T2_CMC2.3 (L2A)
ETH_OUT_LRXP: T2.7 (LINE_RXP), T2_CMC2.1 (L1A)
ETH_OUT_LTXN: T2.6 (LINE_TXN), T2_CMC1.3 (L2A)
ETH_OUT_LTXP: T2.5 (LINE_TXP), T2_CMC1.1 (L1A)
ETH_OUT_RXN: J_ETH_OUT.5, T2_CMC2.4 (L2B), T2_D2.2 (A2)
ETH_OUT_RXP: J_ETH_OUT.4, T2_CMC2.2 (L1B), T2_D2.1 (A1)
ETH_OUT_TXN: J_ETH_OUT.3, T2_CMC1.4 (L2B), T2_D1.2 (A2)
ETH_OUT_TXP: J_ETH_OUT.2, T2_CMC1.2 (L1B), T2_D1.1 (A1)
GND: C_2V5I.2, C_2V5O.2, C_ISO.1, C_VCORE.2, J_CAM_DS.9, J_CANFD.4, J_CHASSIS_R.1, J_PWR.1, J_SWD.4, J_TOF.2, J_TOF_DS.2, Q1.2 (S), R2.2, R_FB1B.2, R_FB3B.2, R_ISET.2, R_REXT.2, T1_D1.3 (K), T1_D2.3 (K), T2_D1.3 (K), T2_D2.3 (K), U2.46 (GND), U2.47 (GND), U2.69 (GND), U2.75 (GND), U2.77 (GND), U2.80 (GND), U2.107 (GND), U2.109 (GND), U2.123 (GND), U2.129 (GND), U3.7 (VSS), U3.49 (VSS), U4.4 (STB), U4.6 (GNDIO), U4.10 (GND1), U5.2 (GND), U5.9 (GND), U5.23 (GND), U5.32 (GND), U5.33, U_REG_1V2.2 (GND), U_REG_1V2_CI.2, U_REG_1V2_CO.2, U_REG_2V5.2 (GND), U_REG_3V3.2 (GND), U_REG_3V3_CI.2, U_REG_3V3_CO.2, U_SOM.A4 (GND), U_SOM.A9 (GND), U_SOM.A14 (GND), U_SOM.A19 (GND), U_SOM.A24 (GND), U_SOM.A29 (GND), U_SOM.A32 (GND), U_SOM.A37 (GND), U_SOM.A42 (GND), U_SOM.A45 (GND), U_SOM.A50 (GND), U_SOM.A55 (GND), U_SOM.B3 (GND), U_SOM.B8 (GND), U_SOM.B13 (GND), U_SOM.B18 (GND), U_SOM.B23 (GND), U_SOM.B28 (GND), U_SOM.B33 (GND), U_SOM.B38 (GND), U_SOM.B43 (GND), U_SOM.B48 (GND), U_SOM.B53 (GND), U_SOM.B56 (GND), U_SOM.B60 (GND), U_SOM.C6 (GND), U_SOM.C12 (GND), U_SOM.C19 (GND), U_SOM.C24 (GND), U_SOM.C31 (GND), U_SOM.C38 (GND), U_SOM.C43 (GND), U_SOM.C48 (GND), U_SOM.C53 (GND), U_SOM.C59 (GND), U_SOM.D3 (GND), U_SOM.D9 (GND), U_SOM.D17 (GND), U_SOM.D22 (GND), U_SOM.D27 (GND), U_SOM.D34 (GND), U_SOM.D39 (GND), U_SOM.D45 (GND), U_SOM.D52 (GND), U_SOM.D57 (GND)
KSZ_ISET: R_ISET.1, U2.127 (ISET)
KSZ_SREXT: R_REXT.1, U2.76 (S_REXT)
KSZ_XI: U2.126 (XI), Y1.1
KSZ_XO: U2.125 (XO), Y1.2
LASER_CATHODE: J_LASER.2, J_LASER_DS.2, Q1.3 (D)
LASER_EN: R1.1, U3.40 (PA22)
LASER_GATE: Q1.1 (G), R1.2, R2.1
MCU_NRST: J_SWD.3, R_NRST.2, U3.4 (NRST)
MCU_SWCLK: J_SWD.2, U3.35 (PA20/SWCLK)
MCU_SWDIO: J_SWD.1, U3.34 (PA19/SWDIO)
MCU_VCORE: C_VCORE.1, U3.48 (VCORE)
PGND: C_ISO.2, D5.3 (K), J_CHASSIS_R.2, R_SHIELD.1
PGND_SHIELD: J_ETH_IN.1, J_ETH_OUT.1, R_SHIELD.2
RGMII_K2S_C: U2.48 (TX_CLK6/REFCLKI6), U_SOM.A18 (X_CPSW_RGMII2_RXC)
RGMII_K2S_CTL: U2.49 (TX_EN6/TX_CTL6), U_SOM.A17 (X_CPSW_RGMII2_RX_CTL)
RGMII_K2S_D0: U2.55 (TXD6_0), U_SOM.A23 (X_CPSW_RGMII2_RD0)
RGMII_K2S_D1: U2.54 (TXD6_1), U_SOM.A22 (X_CPSW_RGMII2_RD1)
RGMII_K2S_D2: U2.53 (TXD6_2), U_SOM.A21 (X_CPSW_RGMII2_RD2)
RGMII_K2S_D3: U2.52 (TXD6_3), U_SOM.A20 (X_CPSW_RGMII2_RD3)
RGMII_S2K_C: U2.57 (RX_CLK6/REFCLKO6), U_SOM.A25 (X_CPSW_RGMII2_TXC)
RGMII_S2K_CTL: U2.58 (RX_DV6/CRS_DV6/RX_CTL6), U_SOM.A26 (X_CPSW_RGMII2_TX_CTL)
RGMII_S2K_D0: U2.65 (RXD6_0), U_SOM.A27 (X_CPSW_RGMII2_TD0)
RGMII_S2K_D1: U2.64 (RXD6_1), U_SOM.A28 (X_CPSW_RGMII2_TD1)
RGMII_S2K_D2: U2.63 (RXD6_2), U_SOM.A30 (X_CPSW_RGMII2_TD2)
RGMII_S2K_D3: U2.62 (RXD6_3), U_SOM.A31 (X_CPSW_RGMII2_TD3)
SOC_PORZ: R_PORZ.2, U_SOM.C52 (X_nRESET_IN)
SW_INT_N: U2.94 (INTRP_N), U3.45 (PA25)
SW_RESET_N: U2.96 (RESET_N), U3.39 (PA21)
SW_SPI_CS: U2.100 (SCS_N), U3.30 (PA15)
SW_SPI_MISO: U2.97 (SDO), U3.31 (PA16)
SW_SPI_MOSI: U2.98 (SDI/SDA/MDIO), U3.33 (PA18)
SW_SPI_SCK: U2.101 (SCL/MDC), U3.32 (PA17)
TPM_PIRQ: U3.46 (PA26), U5.18 (PIRQ#)
TPM_RESET_N: U3.47 (PA27), U5.17 (RST#)
TPM_SPI_CS: U3.8 (PA2), U5.20 (CS#)
TPM_SPI_MISO: U3.10 (PA4), U5.24 (MISO)
TPM_SPI_MOSI: U3.11 (PA5), U5.21 (MOSI)
TPM_SPI_SCK: U3.12 (PA6), U5.19 (SCLK)
UART_A2M: U3.19 (PA11), U_SOM.D38 (X_UART0_TXD)
UART_M2A: U3.18 (PA10), U_SOM.D37 (X_UART0_RXD)
UART_TOF_RX: J_TOF.4, J_TOF_DS.4, U3.17 (PA9)
UART_TOF_TX: J_TOF.3, J_TOF_DS.3, U3.16 (PA8)
U_REG_1V2_FB: R_FB1B.1, R_FB1T.2, U_REG_1V2.5 (FB)
U_REG_1V2_SW: U_REG_1V2.3 (SW), U_REG_1V2_L.1
U_REG_3V3_FB: R_FB3B.1, R_FB3T.2, U_REG_3V3.5 (FB)
U_REG_3V3_SW: U_REG_3V3.3 (SW), U_REG_3V3_L.1

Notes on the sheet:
JAYNE — Nose/Cargo Vision/ToF/Laser | STANDALONE board (NOT a PB2-I cape) | SoM end-state: PHYTEC PCM-071 + carrier (KSZ9477 / MSPM0G3507 / SLB9670 / ISOW1044)
=== Section A: Power Input + Carrier Rails ===
Carrier rails (design decision 2026-07-13): PCM-071 provides NO rail to the carrier; all generated here from +5V. Feedback dividers / inductor / LDO margin are first-pass — verify per TI datasheet design procedures.
=== Section B: PHYTEC phyCORE PCM-071 SoM (U_SOM) ===
=== Section C: Microchip KSZ9477 (U2) ===
=== Section D: MSPM0G3507 (U3) + SLB9670 TPM (U5) ===
=== Section E: ISOW1044 Isolated CAN-FD (U4) ===
=== Section F: Ethernet Ring EMI Chain (in / out) ===
=== Section G: PGND/GND single-point bond ===
=== Section H: Camera / ToF / Laser ===

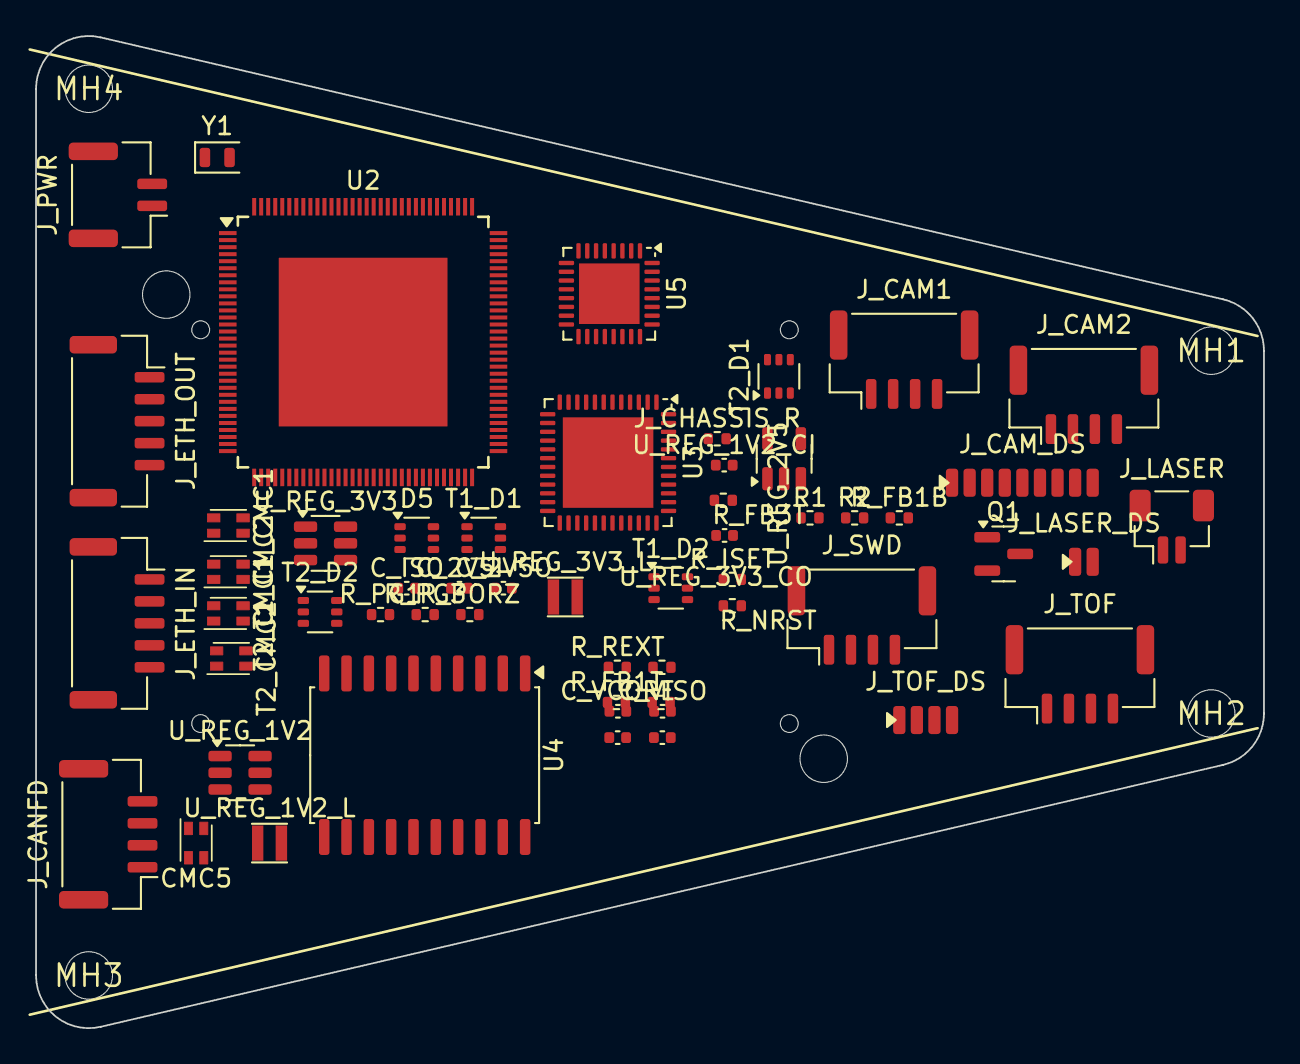
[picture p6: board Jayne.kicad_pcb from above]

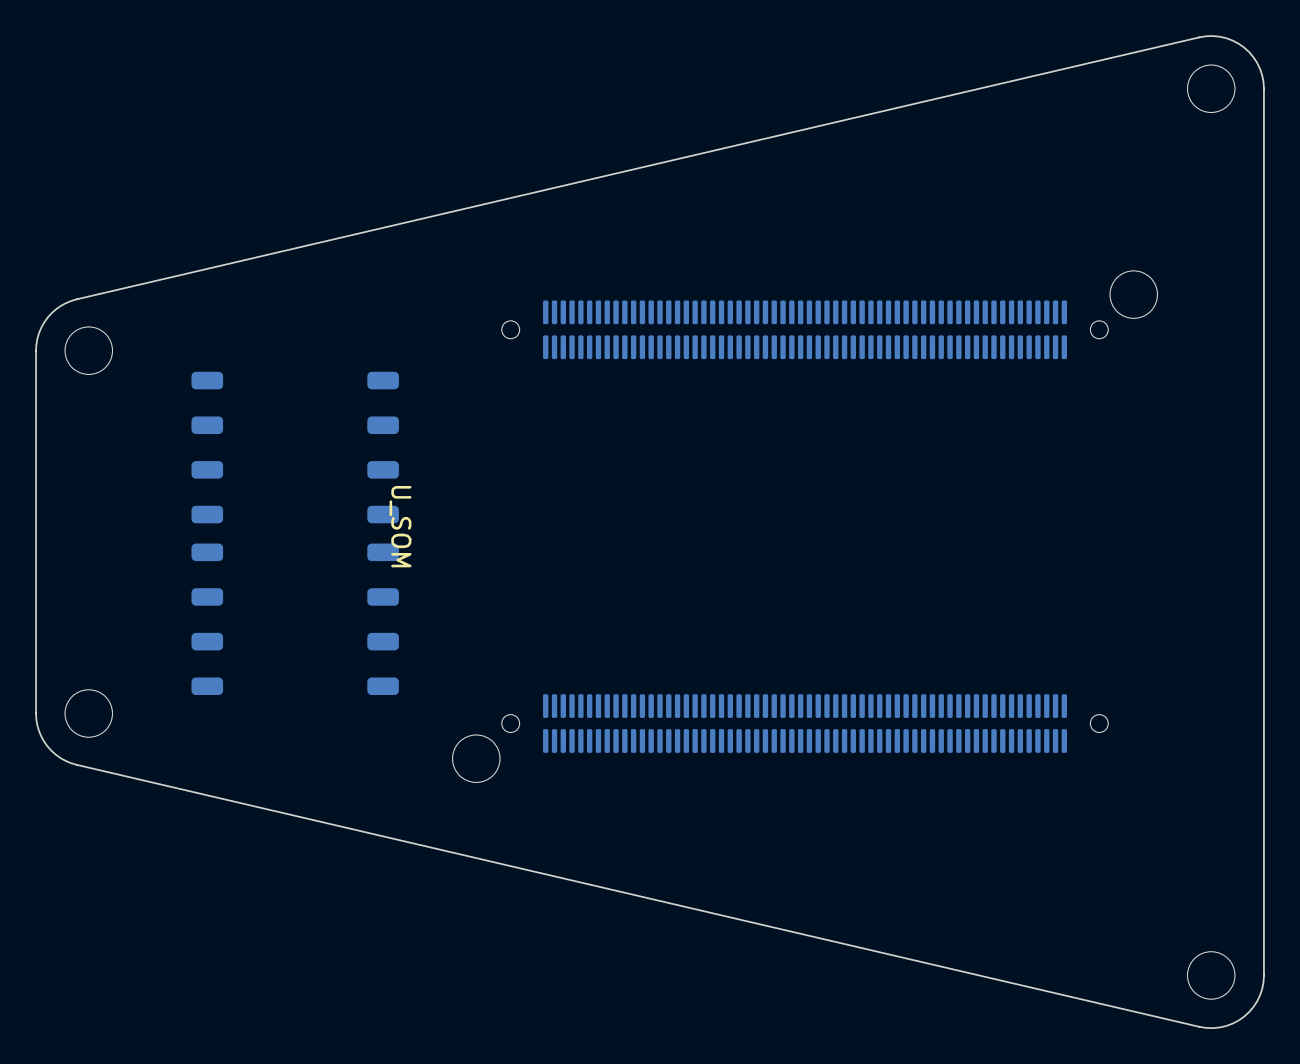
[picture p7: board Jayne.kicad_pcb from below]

Board: 4 copper layers, 69.8 x 56.4 mm, 63 parts (3 on the bottom side), 92 nets, no tracks yet.

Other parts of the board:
MH1, MH2, MH3, MH4: (no value)

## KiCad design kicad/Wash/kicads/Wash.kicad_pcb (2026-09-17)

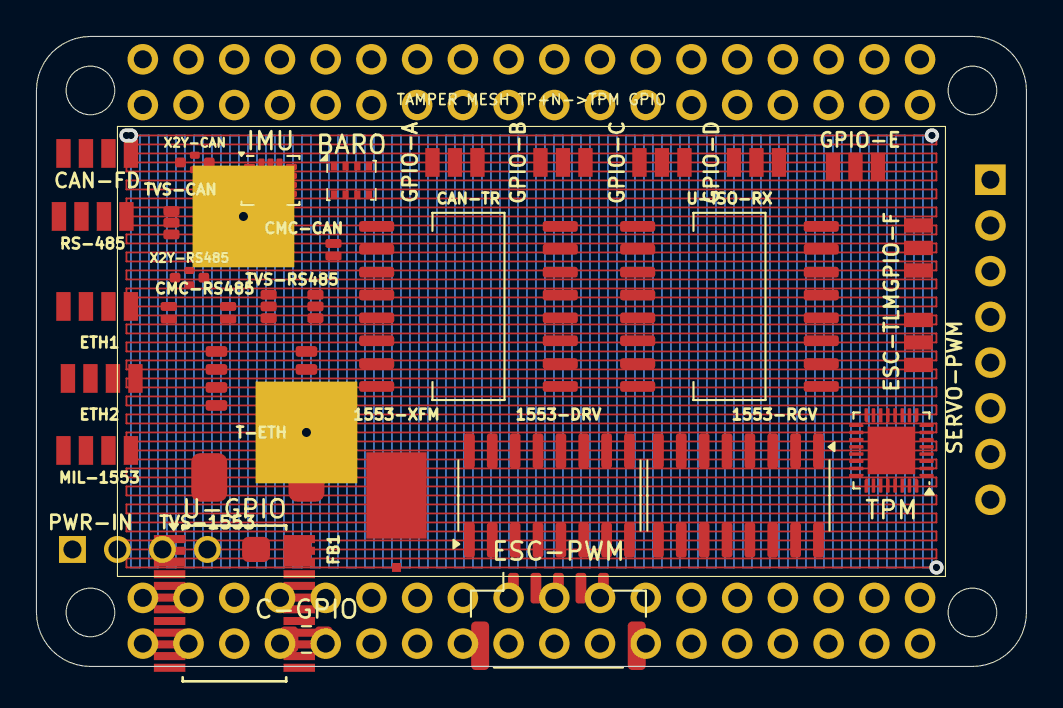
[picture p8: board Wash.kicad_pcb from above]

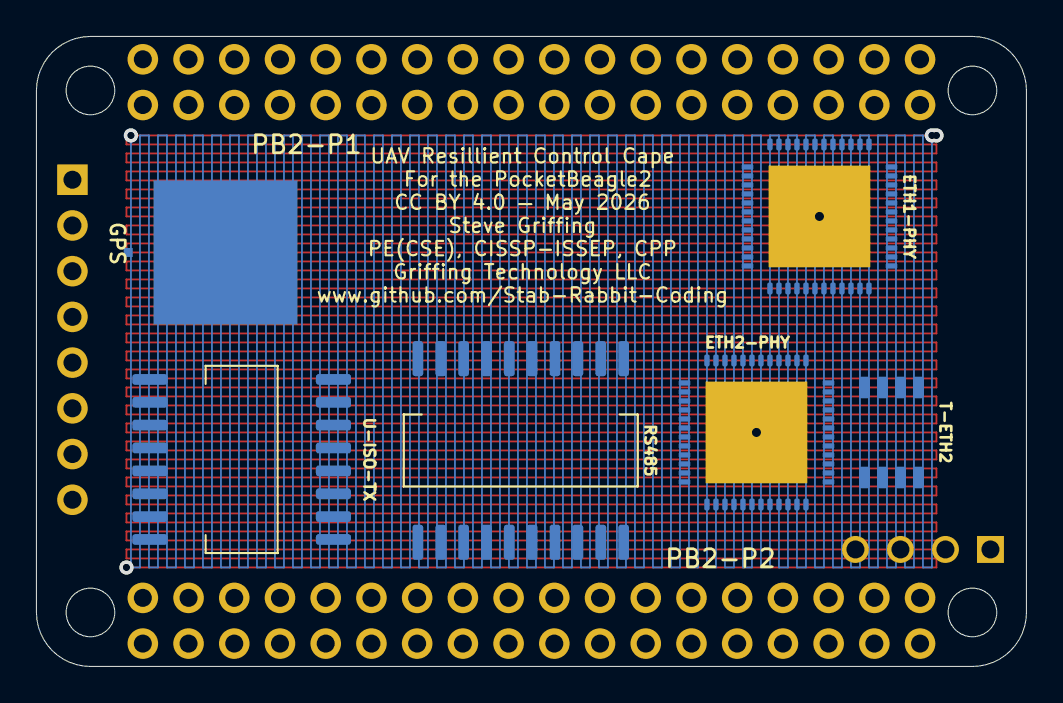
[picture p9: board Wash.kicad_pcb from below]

Board: 4 copper layers, 55.0 x 35.0 mm, 42 parts (8 on the bottom side), 91 nets.

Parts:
1553-DRV: DS26LV31; SOIC-16_3.9x9.9mm_P1.27mm
1553-RCV: DS26LV32; SOIC-16_3.9x9.9mm_P1.27mm
1553-XFM: SM-1553-11; Package
BARO: BMP388; Bosch_LGA-8_2x2.5mm_P0.65mm_ClockwisePinNumbering
C-GPIO: 100nF; C_0805_2012Metric
CAN-FD: JST-GH-4P-CAN; JST_GH_4P
CAN-TR: ISOW1044BDFMR; SOIC-16W_7.5x10.3mm_P1.27mm
CMC-CAN: SRF2012-100Y; Bourns_SRF2012_4T
CMC-RS485: SRF2012-100Y; Bourns_SRF2012_4T
ESC-PWM: JST-GH-5P-ESC; JST_GH_SM05B-GHS-TB_1x05-1MP_P1.25mm_Horizontal
ESC-TLM: JST-GH-3P-ESC-TELEM; JST_GH_3P
ETH1, ETH2: JST-GH-4P-ETH; JST_GH_4P
ETH1-PHY, ETH2-PHY: ADIN1300BCPZ; QFN-48-1EP_7x7mm_P0.5mm_EP5.65x5.65mm
FB1: 742792512; C_0805_2012Metric
GPIO-A: JST-GH-3P-GPIO; JST_GH_3P_V
GPIO-B: JST-GH-3P-GPIO; JST_GH_3P_V
GPIO-C: JST-GH-3P-GPIO; JST_GH_3P_V
GPIO-D: JST-GH-3P-GPIO; JST_GH_3P_V
GPIO-E: JST-GH-3P-GPIO; JST_GH_3P_V
GPIO-F: JST-GH-3P-GPIO; JST_GH_3P_V
GPS: SAM-M10Q-00B; Package
IMU: ICM-42688-P; LGA-14_3x2.5mm_P0.5mm_LayoutBorder3x4y
MIL-1553: JST-GH-4P-1553; JST_GH_4P
PB2-P1: PB2I-P1-2x18; 2x18_P1_Socket
PB2-P2: PB2I-P2-2x18; 2x18_P2_Socket
PWR-IN: Nano-Fit-4P-POWER; Connector_Molex_NanoFit
RS485: ADM2795EBRWZ; SOIC-20W_7.5x12.8mm_P1.27mm
RS-485: JST-GH-4P-RS485; JST_GH_4P
SERVO-PWM: 1x8-SERVO-PWM; Connector_PinHeader_2.54mm
T-ETH, T-ETH2: 749010012A; ETH_XFMR_8P_5x3.5mm
TPM: SLB9670; QFN-32-1EP_4x4mm_P0.4mm_EP2.65x2.65mm
TVS-1553: SMAJ33CA; DO-214AC_SMA
TVS-CAN: PRTR5V0U2X; SOT-363_SC-88
TVS-RS485: PRTR5V0U2X; SOT-363_SC-88
U-GPIO: PCA9555DB; SSOP-24_5.3x8.2mm_P0.65mm
U-ISO-RX: ISO7642FDWRR; SOIC-16W_7.5x10.3mm_P1.27mm
U-ISO-TX: ISO7642FDWRR; SOIC-16W_7.5x10.3mm_P1.27mm
X2Y-CAN, X2Y-RS485: 4.7nF X2Y; X2Y_Cap_4T_0402

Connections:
+3V3: C-GPIO.1, CAN-FD.4, CAN-TR.1, GPIO-A.2, GPIO-B.2, GPIO-C.2, GPIO-D.2, GPIO-E.2, GPIO-F.2, PB2-P1.33, PB2-P1.34, RS485.1, RS-485.4, U-GPIO.24, U-ISO-RX.16, U-ISO-TX.1
+5V: FB1.1, FB1.2, PB2-P1.35, PB2-P2.35, PWR-IN.1, PWR-IN.2
CAN_H: CAN-FD.2, CMC-CAN.1, CMC-CAN.3, TVS-CAN.1
CAN_L: CAN-FD.3, CAN-TR.10, CMC-CAN.2, CMC-CAN.4, TVS-CAN.3
CAN_STB: CAN-TR.3, PB2-P1.14
DSHOT0: ESC-PWM.1, PB2-P1.6
DSHOT1: ESC-PWM.2, PB2-P1.5
DSHOT2: ESC-PWM.3, PB2-P1.4
DSHOT3: ESC-PWM.4, PB2-P1.3
ETH2_LINE_RXN: ETH2.4, T-ETH2.8
ETH2_LINE_RXP: ETH2.3, T-ETH2.7
ETH2_LINE_TXN: ETH2.2, T-ETH2.6
ETH2_LINE_TXP: ETH2.1, T-ETH2.5
ETH2_RXN: ETH2-PHY.5, T-ETH2.4
ETH2_RXP: ETH2-PHY.4, T-ETH2.3
ETH2_TXN: ETH2-PHY.2, T-ETH2.2
ETH2_TXP: ETH2-PHY.1, T-ETH2.1
ETH_LINE_RXN: ETH1.4, T-ETH.8
ETH_LINE_RXP: ETH1.3, T-ETH.7
ETH_LINE_TXN: ETH1.2, T-ETH.6
ETH_LINE_TXP: ETH1.1, T-ETH.5
ETH_RXN: ETH1-PHY.5, T-ETH.4
ETH_RXP: ETH1-PHY.4, T-ETH.3
ETH_TXN: ETH1-PHY.2, T-ETH.2
ETH_TXP: ETH1-PHY.1, T-ETH.1
GND: C-GPIO.2, CAN-FD.1, CAN-TR.8, ESC-PWM.5, ESC-TLM.1, ETH1-PHY.3, ETH1-PHY.6, ETH1-PHY.10, ETH1-PHY.11, ETH1-PHY.12, ETH1-PHY.49, ETH2-PHY.3, ETH2-PHY.6, ETH2-PHY.10, ETH2-PHY.11, ETH2-PHY.12, ETH2-PHY.49, GPIO-A.1, GPIO-B.1, GPIO-C.1, GPIO-D.1, GPIO-E.1, GPIO-F.1, PB2-P1.1, PB2-P1.2, PB2-P1.36, PB2-P2.36, PWR-IN.3, PWR-IN.4, RS485.2, RS485.7, RS485.8, RS-485.1, TVS-1553.1, U-GPIO.2, U-GPIO.3, U-GPIO.12, U-GPIO.21, U-ISO-RX.9, U-ISO-TX.8, X2Y-CAN.1, X2Y-CAN.2, X2Y-CAN.3, X2Y-RS485.1, X2Y-RS485.2, X2Y-RS485.3
GND2_CAN: TVS-CAN.2, X2Y-CAN.4
GND2_ETH: ETH1-PHY.21, ETH1-PHY.22, ETH1-PHY.25, ETH1-PHY.34, ETH1-PHY.36, ETH2-PHY.21, ETH2-PHY.22, ETH2-PHY.25, ETH2-PHY.34, ETH2-PHY.36, U-ISO-RX.8, U-ISO-TX.9
GND2_RS485: TVS-RS485.2, X2Y-RS485.4
GPIO_EXP_A: GPIO-A.3, U-GPIO.4
GPIO_EXP_B: GPIO-B.3, U-GPIO.5
GPIO_EXP_C: GPIO-C.3, U-GPIO.6
GPIO_EXP_D: GPIO-D.3, U-GPIO.7
GPIO_EXP_E: GPIO-E.3, U-GPIO.8
GPIO_EXP_F: GPIO-F.3, U-GPIO.9
I2C1_SCL: PB2-P1.28, U-GPIO.22
I2C1_SDA: PB2-P1.27, U-GPIO.23
IMU_INT2: IMU.14, PB2-P1.18
MCAN0_RX: CAN-TR.4, PB2-P1.15
MCAN0_TX: CAN-TR.2, PB2-P1.16
MDC: U-ISO-TX.6, U-ISO-TX.11
MDC0: ETH1-PHY.19, PB2-P2.18
MDC1: ETH2-PHY.19, PB2-P2.2
MDIO: U-ISO-RX.7, U-ISO-RX.10
MDIO0: ETH1-PHY.18, PB2-P2.17
MDIO1: ETH2-PHY.18, PB2-P2.1
PHY1_INTRN: ETH1-PHY.20, PB2-P2.16, U-ISO-RX.6, U-ISO-RX.11
PHY1_RSTN: ETH1-PHY.35, PB2-P2.15, U-ISO-TX.7, U-ISO-TX.10
PHY2_INTRN: ETH2-PHY.20, PB2-P2.14
PHY2_RSTN: ETH2-PHY.35, PB2-P2.13
PRU_1553_RX_N: 1553-RCV.13, PB2-P1.7
PRU_1553_TX_N: 1553-DRV.6, PB2-P1.9
PRU_1553_TX_P: 1553-DRV.10, PB2-P1.10
RMII0_CRS_DV: ETH1-PHY.32, PB2-P2.29, U-ISO-RX.4, U-ISO-RX.13
RMII0_REF_CLK: ETH1-PHY.29, PB2-P2.27, U-ISO-TX.2, U-ISO-TX.15
RMII0_RXD0: ETH1-PHY.30, PB2-P2.31, U-ISO-RX.2, U-ISO-RX.15
RMII0_RXD1: ETH1-PHY.31, PB2-P2.30, U-ISO-RX.3, U-ISO-RX.14
RMII0_RX_ER: ETH1-PHY.33, PB2-P2.28, U-ISO-RX.5, U-ISO-RX.12
RMII0_TXD0: ETH1-PHY.28, PB2-P2.34, U-ISO-TX.3, U-ISO-TX.14
RMII0_TXD1: ETH1-PHY.27, PB2-P2.33, U-ISO-TX.4, U-ISO-TX.13
RMII0_TX_EN: ETH1-PHY.26, PB2-P2.32, U-ISO-TX.5, U-ISO-TX.12
RMII1_CRS_DV: ETH2-PHY.32, PB2-P2.21
RMII1_REF_CLK: ETH2-PHY.29, PB2-P2.19
RMII1_RXD0: ETH2-PHY.30, PB2-P2.23
RMII1_RXD1: ETH2-PHY.31, PB2-P2.22
RMII1_RX_ER: ETH2-PHY.33, PB2-P2.20
RMII1_TXD0: ETH2-PHY.28, PB2-P2.26
RMII1_TXD1: ETH2-PHY.27, PB2-P2.25
RMII1_TX_EN: ETH2-PHY.26, PB2-P2.24
RS485_A: CMC-RS485.1, CMC-RS485.3, RS-485.2, TVS-RS485.1
RS485_B: CMC-RS485.2, CMC-RS485.4, RS485.15, RS-485.3, TVS-RS485.3
RS485_DE: PB2-P1.11, RS485.4, RS485.5
RS485_RX: PB2-P1.12, RS485.6
RS485_TX: PB2-P1.13, RS485.3
SERVO0: PB2-P2.8, SERVO-PWM.1
SERVO1: PB2-P2.7, SERVO-PWM.2
SERVO2: PB2-P2.6, SERVO-PWM.3
SERVO3: PB2-P2.5, SERVO-PWM.4
SERVO4: PB2-P2.4, SERVO-PWM.5
SERVO5: PB2-P2.3, SERVO-PWM.6
SPI0_CLK: BARO.6, IMU.2, PB2-P1.25, TPM.23
SPI0_CS_BARO: BARO.7, PB2-P1.22
SPI0_CS_IMU: IMU.3, PB2-P1.26
SPI0_CS_TPM: PB2-P1.21, TPM.28
SPI0_MISO: BARO.3, IMU.5, PB2-P1.23, TPM.22
SPI0_MOSI: BARO.5, IMU.1, PB2-P1.24, TPM.21
TPM_IRQN: PB2-P2.12, TPM.24
TPM_RSTN: PB2-P2.11, TPM.1
UART_ESC_RX: ESC-TLM.3, PB2-P1.29
UART_ESC_TX: ESC-TLM.2, PB2-P1.30
VCC2_ETH: ETH1-PHY.7, ETH1-PHY.8, ETH1-PHY.9, ETH1-PHY.40, ETH1-PHY.41, ETH2-PHY.7, ETH2-PHY.8, ETH2-PHY.9, ETH2-PHY.40, ETH2-PHY.41, U-ISO-RX.1, U-ISO-TX.16

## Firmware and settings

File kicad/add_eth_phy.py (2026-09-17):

#!/usr/bin/env python3
"""
add_eth_phy.py — Add one EM-hardened Ethernet port to Wash and TACCO.

Components added:
  ADIN1300BCPZ  : ADI industrial 10/100/1000BASE-T PHY, IEC 61000-4 hardened,
                  RMII interface [REF-IEEE-001 Clause 22], -40/+85 C.
                  Ref: analog.com/media/en/technical-documentation/data-sheets/ADIN1300.pdf
  ISO7642FDWRR  : TI 6-channel 150 Mbps 5 kV digital isolator (SOIC-16W), x2.
                  Isolates RMII bus at same 5 kV reinforced-isolation level as
                  ISOW1044 on CAN [REF-IEC-001 §5.5.2] [REF-VDE-001 Cl.4.3].
                  Ref: ti.com/product/ISO7642
  749010012A    : Wurth SMD 10/100BASE-TX Ethernet transformer with integrated CMC.
                  Provides galvanic isolation on the MDI side, 1500 Vrms per
                  [REF-IEEE-001 Clause 38].  8-pin SMD.
                  Ref: Wurth Electronics 749010012A datasheet.
  JST GH 4P     : JST GH series 4-pin connector for Ethernet harness.
                  TX+/TX-/RX+/RX- on 1.25 mm pitch.  Lightweight, locking.

RMII0 signals are reconnected from the PB2-P2 connector (where no_connect markers
were placed by gen_cape_a2.py / gen_cape_b2.py) through two ISO7642FDWRR isolators
to the ADIN1300 PHY.  RMII1 signals and PHY2 control remain as no_connect (only
one PHY per cape).

For TACCO also removes orphaned PHY-side global_labels left by gen_cape_b2.py.

Usage:
    python3 add_eth_phy.py Wash.kicad_sch
    python3 add_eth_phy.py TACCO.kicad_sch

Author:  Steve Griffing, PE(CSE), CISSP-ISSEP, CPP
License: CC BY 4.0  |  creativecommons.org/licenses/by/4.0
Date:    2026-06-03
References:
    TI ISO7642 datasheet SCDS349 (2022)
    ADI ADIN1300 datasheet (Rev. B, 2022)
    Wurth 749010012A datasheet (10/100BASE-TX SMD transformer)
    JST GH series datasheet
    KiCad S-expression schematic format v20240101
"""

import os
import re
import sys

# ---------------------------------------------------------------------------
# Y-positions on PB2-P2 connector (X=67.54) for RMII0 signals to restore.
# These were replaced with no_connect markers by gen_cape_a2/b2.py.
# ---------------------------------------------------------------------------
RMII0_RESTORE = {
    390.63: "RMII0_TXD0",
    393.17: "RMII0_TXD1",
    395.71: "RMII0_TX_EN",
    398.25: "RMII0_RXD0",
    400.79: "RMII0_RXD1",
    403.33: "RMII0_CRS_DV",
    405.87: "RMII0_RX_ER",
    408.41: "RMII0_REF_CLK",
    431.27: "MDC",
    433.81: "MDIO",
    436.35: "PHY1_INTRN",
    438.89: "PHY1_RSTN",
}

# Orphaned PHY-side labels in TACCO (left by gen_cape_b2.py).
# These are at X=197.30/222.70/347.30/372.70, Y=447-465.
CAPE_B2_ORPHAN_X = {197.30, 222.70, 347.30, 372.70}
CAPE_B2_ORPHAN_Y_RANGE = (440.0, 470.0)


# ---------------------------------------------------------------------------
# Lib-symbol definitions
# ---------------------------------------------------------------------------

ADIN1300_SYM = """    (symbol "ADIN1300"
      (pin_names (offset 0.254))
      (pin_numbers (hide yes))
      (property "Reference" "U" (at 0 -19.05 0)
        (effects (font (size 1.27 1.27))))
      (property "Value" "ADIN1300" (at 0 19.05 0)
        (effects (font (size 1.27 1.27))))
      (property "Footprint" "Package_LGA:LGA-48_7x7mm_P0.5mm" (at 0 0 0)
        (effects (font (size 1.27 1.27)) (hide yes)))
      (property "Datasheet"
        "https://www.analog.com/media/en/technical-documentation/data-sheets/ADIN1300.pdf"
        (at 0 0 0) (effects (font (size 1.27 1.27)) (hide yes)))
      (symbol "ADIN1300_0_1"
        (rectangle (start -12.70 17.78) (end 12.70 -17.78)
          (stroke (width 0) (type default)) (fill (type background))))
      (symbol "ADIN1300_1_1"
        (pin input line (at -17.78 13.97 0) (length 2.54)
          (name "REF_CLK" (effects (font (size 1.016 1.016))))
          (number "1" (effects (font (size 1.016 1.016)))))
        (pin input line (at -17.78 11.43 0) (length 2.54)
          (name "TXD0" (effects (font (size 1.016 1.016))))
          (number "2" (effects (font (size 1.016 1.016)))))
        (pin input line (at -17.78 8.89 0) (length 2.54)
          (name "TXD1" (effects (font (size 1.016 1.016))))
          (number "3" (effects (font (size 1.016 1.016)))))
        (pin input line (at -17.78 6.35 0) (length 2.54)
          (name "TX_EN" (effects (font (size 1.016 1.016))))
          (number "4" (effects (font (size 1.016 1.016)))))
        (pin output line (at -17.78 3.81 0) (length 2.54)
          (name "RXD0" (effects (font (size 1.016 1.016))))
          (number "5" (effects (font (size 1.016 1.016)))))
        (pin output line (at -17.78 1.27 0) (length 2.54)
          (name "RXD1" (effects (font (size 1.016 1.016))))
          (number "6" (effects (font (size 1.016 1.016)))))
        (pin output line (at -17.78 -1.27 0) (length 2.54)
          (name "CRS_DV" (effects (font (size 1.016 1.016))))
          (number "7" (effects (font (size 1.016 1.016)))))
        (pin output line (at -17.78 -3.81 0) (length 2.54)
          (name "RX_ER" (effects (font (size 1.016 1.016))))
          (number "8" (effects (font (size 1.016 1.016)))))
        (pin input line (at -17.78 -6.35 0) (length 2.54)
          (name "MDC" (effects (font (size 1.016 1.016))))
          (number "9" (effects (font (size 1.016 1.016)))))
        (pin bidirectional line (at -17.78 -8.89 0) (length 2.54)
          (name "MDIO" (effects (font (size 1.016 1.016))))
          (number "10" (effects (font (size 1.016 1.016)))))
        (pin input line (at -17.78 -11.43 0) (length 2.54)
          (name "RESET_N" (effects (font (size 1.016 1.016))))
          (number "11" (effects (font (size 1.016 1.016)))))
        (pin output line (at -17.78 -13.97 0) (length 2.54)
          (name "INT_N" (effects (font (size 1.016 1.016))))
          (number "12" (effects (font (size 1.016 1.016)))))
        (pin output line (at 17.78 8.89 180) (length 2.54)
          (name "MDI_TXP" (effects (font (size 1.016 1.016))))
          (number "13" (effects (font (size 1.016 1.016)))))
        (pin output line (at 17.78 6.35 180) (length 2.54)
          (name "MDI_TXN" (effects (font (size 1.016 1.016))))
          (number "14" (effects (font (size 1.016 1.016)))))
        (pin input line (at 17.78 -6.35 180) (length 2.54)
          (name "MDI_RXP" (effects (font (size 1.016 1.016))))
          (number "15" (effects (font (size 1.016 1.016)))))
        (pin input line (at 17.78 -8.89 180) (length 2.54)
          (name "MDI_RXN" (effects (font (size 1.016 1.016))))
          (number "16" (effects (font (size 1.016 1.016)))))
        (pin power_in line (at 17.78 13.97 180) (length 2.54)
          (name "VDD" (effects (font (size 1.016 1.016))))
          (number "17" (effects (font (size 1.016 1.016)))))
        (pin power_in line (at 17.78 11.43 180) (length 2.54)
          (name "VDDIO" (effects (font (size 1.016 1.016))))
          (number "18" (effects (font (size 1.016 1.016)))))
        (pin power_in line (at 17.78 -13.97 180) (length 2.54)
          (name "GND" (effects (font (size 1.016 1.016))))
          (number "19" (effects (font (size 1.016 1.016)))))
      )
    )
"""

ISO7642_SYM = """    (symbol "ISO7642FDWRR"
      (pin_names (offset 0.254))
      (pin_numbers (hide yes))
      (property "Reference" "U" (at 0 -12.70 0)
        (effects (font (size 1.27 1.27))))
      (property "Value" "ISO7642FDWRR" (at 0 12.70 0)
        (effects (font (size 1.27 1.27))))
      (property "Footprint" "Package_SO:SOIC-16W_7.5x10.3mm_P1.27mm" (at 0 0 0)
        (effects (font (size 1.27 1.27)) (hide yes)))
      (property "Datasheet" "https://www.ti.com/lit/ds/symlink/iso7642.pdf" (at 0 0 0)
        (effects (font (size 1.27 1.27)) (hide yes)))
      (symbol "ISO7642FDWRR_0_1"
        (rectangle (start -7.62 10.16) (end 7.62 -10.16)
          (stroke (width 0) (type default)) (fill (type background)))
        (polyline
          (pts (xy 0 10.16) (xy 0 -10.16))
          (stroke (width 0.127) (type dash)) (fill (type none))))
      (symbol "ISO7642FDWRR_1_1"
        (pin power_in line (at -12.70 8.89 0) (length 2.54)
          (name "GND_A" (effects (font (size 1.016 1.016))))
          (number "1" (effects (font (size 1.016 1.016)))))
        (pin input line (at -12.70 6.35 0) (length 2.54)
          (name "INA1" (effects (font (size 1.016 1.016))))
          (number "2" (effects (font (size 1.016 1.016)))))
        (pin input line (at -12.70 3.81 0) (length 2.54)
          (name "INA2" (effects (font (size 1.016 1.016))))
          (number "3" (effects (font (size 1.016 1.016)))))
        (pin input line (at -12.70 1.27 0) (length 2.54)
          (name "INA3" (effects (font (size 1.016 1.016))))
          (number "4" (effects (font (size 1.016 1.016)))))
        (pin input line (at -12.70 -1.27 0) (length 2.54)
          (name "INA4" (effects (font (size 1.016 1.016))))
          (number "5" (effects (font (size 1.016 1.016)))))
        (pin input line (at -12.70 -3.81 0) (length 2.54)
          (name "INA5" (effects (font (size 1.016 1.016))))
          (number "6" (effects (font (size 1.016 1.016)))))
        (pin input line (at -12.70 -6.35 0) (length 2.54)
          (name "INA6" (effects (font (size 1.016 1.016))))
          (number "7" (effects (font (size 1.016 1.016)))))
        (pin power_in line (at -12.70 -8.89 0) (length 2.54)
          (name "VCC_A" (effects (font (size 1.016 1.016))))
          (number "8" (effects (font (size 1.016 1.016)))))
        (pin power_in line (at 12.70 8.89 180) (length 2.54)
          (name "VCC_B" (effects (font (size 1.016 1.016))))
          (number "9" (effects (font (size 1.016 1.016)))))
        (pin power_in line (at 12.70 6.35 180) (length 2.54)
          (name "GND_B" (effects (font (size 1.016 1.016))))
          (number "10" (effects (font (size 1.016 1.016)))))
        (pin output line (at 12.70 3.81 180) (length 2.54)
          (name "OUTB1" (effects (font (size 1.016 1.016))))
          (number "11" (effects (font (size 1.016 1.016)))))
        (pin output line (at 12.70 1.27 180) (length 2.54)
          (name "OUTB2" (effects (font (size 1.016 1.016))))
          (number "12" (effects (font (size 1.016 1.016)))))
        (pin output line (at 12.70 -1.27 180) (length 2.54)
          (name "OUTB3" (effects (font (size 1.016 1.016))))
          (number "13" (effects (font (size 1.016 1.016)))))
        (pin output line (at 12.70 -3.81 180) (length 2.54)
          (name "OUTB4" (effects (font (size 1.016 1.016))))
          (number "14" (effects (font (size 1.016 1.016)))))
        (pin output line (at 12.70 -6.35 180) (length 2.54)
          (name "OUTB5" (effects (font (size 1.016 1.016))))
          (number "15" (effects (font (size 1.016 1.016)))))
        (pin output line (at 12.70 -8.89 180) (length 2.54)
          (name "OUTB6" (effects (font (size 1.016 1.016))))
          (number "16" (effects (font (size 1.016 1.016)))))
      )
    )
"""

ETH_XFMR_SYM = """    (symbol "ETH_XFMR"
      (pin_names (offset 0.254))
      (pin_numbers (hide yes))
      (property "Reference" "T" (at 0 -8.89 0)
        (effects (font (size 1.27 1.27))))
      (property "Value" "749010012A" (at 0 8.89 0)
        (effects (font (size 1.27 1.27))))
      (property "Footprint"
        "Transformer_SMD:Wurth_749010012A_10-100BASE-TX" (at 0 0 0)
        (effects (font (size 1.27 1.27)) (hide yes)))
      (property "Datasheet"
        "https://www.we-online.com/catalog/datasheet/749010012A.pdf" (at 0 0 0)
        (effects (font (size 1.27 1.27)) (hide yes)))
      (symbol "ETH_XFMR_0_1"
        (rectangle (start -5.08 7.62) (end 5.08 -7.62)
          (stroke (width 0) (type default)) (fill (type background)))
        (polyline
          (pts (xy 0 7.62) (xy 0 -7.62))
          (stroke (width 0.127) (type dash)) (fill (type none))))
      (symbol "ETH_XFMR_1_1"
        (pin input line (at -10.16 5.08 0) (length 2.54)
          (name "PHY_TX+" (effects (font (size 1.016 1.016))))
          (number "1" (effects (font (size 1.016 1.016)))))
        (pin input line (at -10.16 2.54 0) (length 2.54)
          (name "PHY_TX-" (effects (font (size 1.016 1.016))))
          (number "2" (effects (font (size 1.016 1.016)))))
        (pin output line (at -10.16 -2.54 0) (length 2.54)
          (name "PHY_RX+" (effects (font (size 1.016 1.016))))
          (number "3" (effects (font (size 1.016 1.016)))))
        (pin output line (at -10.16 -5.08 0) (length 2.54)
          (name "PHY_RX-" (effects (font (size 1.016 1.016))))
          (number "4" (effects (font (size 1.016 1.016)))))
        (pin output line (at 10.16 5.08 180) (length 2.54)
          (name "LINE_TX+" (effects (font (size 1.016 1.016))))
          (number "5" (effects (font (size 1.016 1.016)))))
        (pin output line (at 10.16 2.54 180) (length 2.54)
          (name "LINE_TX-" (effects (font (size 1.016 1.016))))
          (number "6" (effects (font (size 1.016 1.016)))))
        (pin input line (at 10.16 -2.54 180) (length 2.54)
          (name "LINE_RX+" (effects (font (size 1.016 1.016))))
          (number "7" (effects (font (size 1.016 1.016)))))
        (pin input line (at 10.16 -5.08 180) (length 2.54)
          (name "LINE_RX-" (effects (font (size 1.016 1.016))))
          (number "8" (effects (font (size 1.016 1.016)))))
      )
    )
"""

JST_GH4_SYM = """    (symbol "Conn_JST_GH_04P"
      (pin_names (offset 0.254))
      (pin_numbers (hide yes))
      (property "Reference" "J" (at 0 -7.62 0)
        (effects (font (size 1.27 1.27))))
      (property "Value" "JST_GH_04P" (at 0 7.62 0)
        (effects (font (size 1.27 1.27))))
      (property "Footprint"
        "Connector_JST:JST_GH_SM04B-GHS-TB_1x04-1MP_P1.25mm_Horizontal"
        (at 0 0 0) (effects (font (size 1.27 1.27)) (hide yes)))
      (property "Datasheet" "https://www.jst-mfg.com/product/pdf/eng/eGH.pdf"
        (at 0 0 0) (effects (font (size 1.27 1.27)) (hide yes)))
      (symbol "Conn_JST_GH_04P_0_1"
        (rectangle (start -3.81 5.08) (end 3.81 -5.08)
          (stroke (width 0) (type default)) (fill (type background))))
      (symbol "Conn_JST_GH_04P_1_1"
        (pin passive line (at -8.89 3.81 0) (length 2.54)
          (name "TX+" (effects (font (size 1.016 1.016))))
          (number "1" (effects (font (size 1.016 1.016)))))
        (pin passive line (at -8.89 1.27 0) (length 2.54)
          (name "TX-" (effects (font (size 1.016 1.016))))
          (number "2" (effects (font (size 1.016 1.016)))))
        (pin passive line (at -8.89 -1.27 0) (length 2.54)
          (name "RX+" (effects (font (size 1.016 1.016))))
          (number "3" (effects (font (size 1.016 1.016)))))
        (pin passive line (at -8.89 -3.81 0) (length 2.54)
          (name "RX-" (effects (font (size 1.016 1.016))))
          (number "4" (effects (font (size 1.016 1.016)))))
      )
    )
"""


# ---------------------------------------------------------------------------
# S-expression helper
# ---------------------------------------------------------------------------


def find_balanced(text: str, start: int) -> int:
    """Return index past closing ')' of balanced S-expr beginning at start."""
    depth = 0
    i = start
    while i < len(text):
        if text[i] == "(":
            depth += 1
        elif text[i] == ")":
            depth -= 1
            if depth == 0:
                return i + 1
        i += 1
    return len(text)


# ---------------------------------------------------------------------------
# UUID factory
# ---------------------------------------------------------------------------


class UUIDFactory:
    """Sequential UUID generator with a fixed prefix."""

    def __init__(self, prefix: str, start: int = 950_000_000_001):
        self._prefix = prefix
        self._counter = start

    def next(self) -> str:
        uid = f"{self._prefix}{self._counter:012d}"
        self._counter += 1
        return uid


# ---------------------------------------------------------------------------
# Transformation helpers
# ---------------------------------------------------------------------------


def insert_lib_symbols(content: str, new_syms: str) -> str:
    """Insert lib_symbol definitions just before the closing ) of lib_symbols."""
    # Find the end of (lib_symbols ...) block.
    idx = content.find("  (lib_symbols")
    if idx == -1:
        idx = content.find("(lib_symbols")
    end = find_balanced(content, idx)
    # Insert before the final closing paren of lib_symbols.
    return content[: end - 1] + new_syms + content[end - 1 :]


def insert_before_sheet_instances(content: str, new_text: str) -> str:
    """Insert new_text immediately before the (sheet_instances ...) block."""
    marker = "  (sheet_instances"
    idx = content.rfind(marker)
    if idx == -1:
        marker = "(sheet_instances"
        idx = content.rfind(marker)
    if idx == -1:
        return content + new_text
    return content[:idx] + new_text + "\n" + content[idx:]


def remove_noconnects_at_y(content: str, y_values: set) -> str:
    """Remove no_connect markers at X=67.54 for specified Y values."""
    for y in y_values:
        # Flexible match: allow slight float formatting variation.
        pattern = (
            r"\n?\s*\(no_connect \(at 67\.54 "
            + re.escape(f"{y:.2f}")
            + r'\) \(uuid "[^"]+"\)\)'
        )
        content = re.sub(pattern, "", content)
    return content


def remove_orphan_labels_cape_b2(content: str) -> str:
    """
    Remove orphaned global_labels at X in CAPE_B2_ORPHAN_X and
    Y in CAPE_B2_ORPHAN_Y_RANGE — left by gen_cape_b2.py when
    DP83825I instances were removed but their attached labels were not.
    """
    x_pattern = "|".join(re.escape(f"{x:.2f}") for x in CAPE_B2_ORPHAN_X)
    pattern = (
        r'\n?\s*\(global_label "[^"]*" \(shape [^)]+\) \(at '
        r"(?:" + x_pattern + r") "
        r"(?:44[0-9]\.[0-9]+|4[56][0-9]\.[0-9]+|470\.[0-9]+) "
        r'[0-9]+\)[\s\S]*?\(property "Intersheet References"[\s\S]*?\)\)'
    )
    # Use non-greedy match per label block.
    content = re.sub(
        r'\n?\s*\(global_label "[^"]*" \(shape bidirectional\) \(at '
        r"(?:197\.30|222\.70|347\.30|372\.70) "
        r"4[4-6][0-9]\.[0-9]+ [0-9]+\)"
        r"[\s\S]*?"
        r'\(property "Intersheet References" "\$\{INTERSHEET_REFS\}"'
        r"[\s\S]*?\)\)",
        "",
        content,
    )
    return content


# ---------------------------------------------------------------------------
# KiCad element generators
# ---------------------------------------------------------------------------


def make_global_label(
    name: str, x: float, y: float, angle: int, uid: str, ref_uid: str
) -> str:
    """Return a KiCad global_label S-expression string."""
    return (
        f'  (global_label "{name}" (shape bidirectional) (at {x:.2f} {y:.2f} {angle})\n'
        f"    (effects (font (size 1.016 1.016)))\n"
        f'    (uuid "{uid}")\n'
        f'    (property "Intersheet References" "${{INTERSHEET_REFS}}" '
        f"(at {x:.2f} {y:.2f} 0)\n"
        f"      (effects (font (size 1.016 1.016)) (hide yes))))\n"
    )


def make_power_symbol(
    lib_id: str, x: float, y: float, ref: str, uid: str, pin_uid: str
) -> str:
    """Return a KiCad power symbol instance S-expression."""
    val_dy = -2.54 if lib_id == "GND" else 2.54
    return (
        f'  (symbol (lib_id "{lib_id}") (at {x:.2f} {y:.2f} 0)\n'
        f"    (unit 1) (exclude_from_sim no) (in_bom no) (on_board yes) (dnp no)\n"
        f'    (uuid "{uid}")\n'
        f'    (property "Reference" "{ref}" (at {x:.2f} {y:.2f} 0)\n'
        f"      (effects (font (size 1.27 1.27)) (hide yes)))\n"
        f'    (property "Value" "{lib_id}" (at {x:.2f} {y + val_dy:.2f} 0)\n'
        f"      (effects (font (size 1.27 1.27))))\n"
        f'    (pin "1" (uuid "{pin_uid}")))\n'
    )


def make_iso7642_instance(
    ref: str, x: float, y: float, uids: list, pin_uids: list
) -> str:
    """Build a ISO7642FDWRR symbol instance."""
    return (
        f'  (symbol (lib_id "ISO7642FDWRR") (at {x:.2f} {y:.2f} 0)\n'
        f"    (unit 1) (exclude_from_sim no) (in_bom yes) (on_board yes) (dnp no)\n"
        f'    (uuid "{uids[0]}")\n'
        f'    (property "Reference" "{ref}" (at {x:.2f} {y - 13.97:.2f} 0)\n'
        f"      (effects (font (size 1.27 1.27))))\n"
        f'    (property "Value" "ISO7642FDWRR" (at {x:.2f} {y + 13.97:.2f} 0)\n'
        f"      (effects (font (size 1.27 1.27))))\n"
        f'    (property "Footprint" "Package_SO:SOIC-16W_7.5x10.3mm_P1.27mm"'
        f" (at 0 0 0) (effects (font (size 1.27 1.27)) (hide yes)))\n"
        + "".join(
            f'    (pin "{n}" (uuid "{pu}"))\n'
            for n, pu in zip(
                [
                    "1",
                    "2",
                    "3",
                    "4",
                    "5",
                    "6",
                    "7",
                    "8",
                    "9",
                    "10",
                    "11",
                    "12",
                    "13",
                    "14",
                    "15",
                    "16",
                ],
                pin_uids,
            )
        )
        + "  )\n"
    )
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

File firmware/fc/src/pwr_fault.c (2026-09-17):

/**
 * @file    pwr_fault.c
 * @brief   Power fault monitor and load-shedding manager — implementation.
 *
 * Author:  Steve Griffing, PE(CSE), CISSP-ISSEP, CPP
 * License: CC BY 4.0 — creativecommons.org/licenses/by/4.0
 *
 * Implements the power fault state machine described in pwr_fault.h.
 *
 * INA226 I2C address layout on FlightEngineer (all on i2c_dev_pdb bus):
 *   0x40 — ESC1 (Port Fwd, EDF0)
 *   0x41 — ESC2 (Port Aft,  EDF1)
 *   0x42 — ESC3 (Stbd Fwd,  EDF2)
 *   0x43 — ESC4 (Stbd Aft,  EDF3)
 *   0x44 — Main bus monitor
 *   0x08 — BQ76930 cell monitor
 *
 * Shunt resistor values (see FlightEngineer.md §INA226 Calibration):
 *   ESC channels: 1 mΩ, I_max = 60 A
 *   Main bus:     1 mΩ, I_max = 75 A
 *
 * References:
 *   [1] pwr_fault.h — API and threshold documentation.
 *   [2] docs/POWER_DISTRIBUTION.md — load analysis and fault matrix.
 *
 * Target platform: PocketBeagle 2 Industrial (AM6254), Debian Trixie.
 */

#include "pwr_fault.h"

#include <errno.h>
#include <stddef.h>
#include <stdlib.h>
#include <string.h>

/* ---------------------------------------------------------------------------
 * INA226 I2C addresses and shunt configuration
 * ---------------------------------------------------------------------------*/

/** I2C addresses for ESC current monitors on FlightEngineer. */
static const uint8_t ESC_I2C_ADDR[PWR_FAULT_ESC_COUNT] = {
    0x40U, 0x41U, 0x42U, 0x43U
};

/** I2C address for main bus current monitor. */
#define MAIN_BUS_I2C_ADDR   (0x44U)

/** Shunt resistance for ESC monitors (mΩ). */
#define ESC_SHUNT_MOHM      (1U)

/** Maximum current for ESC monitors (mA). */
#define ESC_IMAX_MA         (60000U)

/** Shunt resistance for main bus monitor (mΩ). */
#define MAIN_SHUNT_MOHM     (1U)

/** Maximum current for main bus monitor (mA). */
#define MAIN_IMAX_MA        (75000U)

/* ---------------------------------------------------------------------------
 * Poll divisor for cell monitor
 * Evaluated every CELL_DIVISOR calls to pwr_fault_poll().
 * ---------------------------------------------------------------------------*/
#define CELL_POLL_DIVISOR   (PWR_FAULT_POLL_HZ / PWR_FAULT_CELL_POLL_HZ)

/* ---------------------------------------------------------------------------
 * Internal context
 * ---------------------------------------------------------------------------*/

struct pwr_fault_ctx {
    /* INA226 driver contexts: [0..PWR_FAULT_ESC_COUNT-1] = ESC, [PWR_FAULT_ESC_COUNT] = main. */
    bmon_ina2xx_ctx_t  *ina[PWR_FAULT_ESC_COUNT + 1U];

    /* BQ76930 cell monitor. */
    cell_mon_ctx_t     *cell;

    /* Snapshot of most recent measurement. */
    pwr_fault_snapshot_t snap;

    /* Current fault state. */
    pwr_fault_state_t   state;

    /* Per-ESC sustained-overcurrent timer (ms-equivalent poll count). */
    uint32_t            esc_overcurrent_ticks[PWR_FAULT_ESC_COUNT];

    /* Poll counter for cell-monitor decimation. */
    uint32_t            poll_count;

    /* Load-shedding callback. */
    void (*shed_fn)(pwr_fault_state_t, void *);
    void *shed_user_data;
};

/* ---------------------------------------------------------------------------
 * Internal helpers
 * ---------------------------------------------------------------------------*/

/**
 * @brief Evaluate voltage-based fault state from snapshot values.
 *
 * Returns the severity level implied by the current pack/cell voltages,
 * WITHOUT applying hysteresis (hysteresis is applied at the transition site).
 */
static pwr_fault_state_t voltage_state(const pwr_fault_snapshot_t *snap)
{
    uint32_t min_cell = snap->min_cell_mv;
    uint32_t pack     = snap->pack_mv;

    if (min_cell < PWR_FAULT_CELL_EMERG_MV || pack < PWR_FAULT_PACK_EMERG_MV) {
        return PWR_STATE_EMERGENCY;
    }
    if (min_cell < PWR_FAULT_CELL_CRITICAL_MV || pack < PWR_FAULT_PACK_CRITICAL_MV) {
        return PWR_STATE_CRITICAL;
    }
    if (min_cell < PWR_FAULT_CELL_WARN_MV || pack < PWR_FAULT_PACK_WARN_MV) {
        return PWR_STATE_WARN;
    }
    return PWR_STATE_NORMAL;
}

/**
 * @brief Evaluate current-based fault state from snapshot values.
 */
static pwr_fault_state_t current_state(const pwr_fault_snapshot_t *snap)
{
    uint32_t i;

    if (snap->main_current_ma > (int32_t)PWR_FAULT_MAIN_CRITICAL_MA) {
        return PWR_STATE_CRITICAL;
    }
    if (snap->main_current_ma > (int32_t)PWR_FAULT_MAIN_WARN_MA) {
        return PWR_STATE_WARN;
    }

    for (i = 0U; i < PWR_FAULT_ESC_COUNT; i++) {
        if (snap->esc_fault[i] == ESC_DISARMED) {
            return PWR_STATE_CRITICAL;
        }
        if (snap->esc_fault[i] == ESC_CRIT) {
            return PWR_STATE_CRITICAL;
        }
        if (snap->esc_fault[i] == ESC_WARN) {
            return PWR_STATE_WARN;
        }
    }
    return PWR_STATE_NORMAL;
}

/**
 * @brief Apply hysteresis when transitioning to a lower severity state.
 *
 * A state transition downward requires that the triggering voltage recover by
 * PWR_FAULT_HYST_MV above the threshold that caused the transition.
 *
 * Implemented by raising the effective transition threshold: if the computed
 * new state is below current, only allow the transition if min_cell exceeds
 * the current-level threshold + hysteresis.
 */
static pwr_fault_state_t apply_hysteresis(pwr_fault_state_t current,
                                          pwr_fault_state_t computed,
                                          uint32_t          min_cell_mv)
{
    uint32_t hyst_threshold_mv;

    if (computed >= current) {
        /* Worsening or unchanged — no hysteresis needed. */
        return computed;
    }

    /* Determine the voltage that would exit the current state with hysteresis. */
    switch (current) {
        case PWR_STATE_EMERGENCY:
            hyst_threshold_mv = PWR_FAULT_CELL_EMERG_MV + PWR_FAULT_HYST_MV;
            break;
        case PWR_STATE_CRITICAL:
            hyst_threshold_mv = PWR_FAULT_CELL_CRITICAL_MV + PWR_FAULT_HYST_MV;
            break;
        case PWR_STATE_WARN:
            hyst_threshold_mv = PWR_FAULT_CELL_WARN_MV + PWR_FAULT_HYST_MV;
            break;
        default:
            return computed;
    }

    if (min_cell_mv < hyst_threshold_mv) {
        /* Voltage has not recovered enough to leave current state. */
        return current;
    }
    return computed;
}

/* ---------------------------------------------------------------------------
 * Public API
 * ---------------------------------------------------------------------------*/
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

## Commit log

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2026-06-04 Add EMI-hardened avionics variant schematics, PCBs, and transform scripts
    CAPE-A-2 (Flight Control & Sensor Cape — EMI-hardened):
    - SCH: ATA6561→ISOW1044BDFMR (5kV reinforced CAN isolation + DC/DC)
    - SCH: MAX3485E→ADM2795EBRWZ (5kV reinforced RS-485 isolation + DC/DC)
    - SCH: Both DP83825I PHYs removed; ADIN1300BCPZ + 2×ISO7642FDWRR ETH stack added
    - SCH: SRF2012-100Y CMCs on CAN/RS-485 field lines; PRTR5V0U2X TVS arrays
    - SCH: SMAJ33CA 1553 TVS; Würth 742792512 ferrite bead; X2Y bridging caps
    - SCH: JST GH 4P ETH harness (no RJ45); Würth 749010012A SMD ETH transformer
    - PCB: SOIC-16W land pattern for ISOW1044BDFMR, SOIC-20W for ADM2795EBRWZ
    - PCB: LFCSP-48 (7×7mm 0.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
    [CAPE-A-2.kicad_pcb, CAPE-A-2.kicad_sch, CAPE-B-2.kicad_pcb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]
2026-06-04 Add magnetometer, battery monitor, SBUS/XCVR mux to Cape-A/B; update v2 EMI variants
    Cape-A-1.kicad_sch (via add_sensors_sbus.py):
    - QMC5883L 3-axis magnetometer on I2C1 with GPIO_MAG_DRDY output
    - INA219AIDR battery voltage monitor on I2C1 (voltage-only, IN+/IN- tied)
    - J_VBAT JST GH 2P connector for VBAT_MON_P/GND
    - J_SBUS JST GH 3P → 100R R_SBUS → 74LVC1G14 Schmitt inverter → UART_SBUS_RX
    (SBUS is inverted UART 100kbaud 8E2; inverter restores standard logic)
    Cape-B-1.kicad_sch (via add_sensors_sbus.py):
    - J_XCVR JST GH 6P shared connector (GND/+5V/TX/RX_RAW/PTT_N/+3V3)
    - 74LVC1G14 U_SBUS_B inverter on XCVR_RX_RAW → SBUS_INV_RX
    - SW1 2-position DIP switch: SW1-1=XCVR direct path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
    [CAPE-A-1.kicad_sch, CAPE-A-2.kicad_sch, CAPE-B-1.kicad_sch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]
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2026-06-04 Phase 6: add DTS overlays, serenity-common, and FC sensor drivers
    Device tree overlays (avionics/firmware/dts/):
    - cape-a v1: add I2C1 (QMC5883L@0x0D, INA219@0x40), UART2 SBUS pinmux
    - cape-a v2: new overlay for MMC5983MA@0x30, INA226@0x40, ADIN1300BCPZ
    - cape-b v1: update UART5 comment for DIP-switch XCVR/SBUS dual mode
    - cape-b v2: new overlay for ADIN1300BCPZ, EMI-hardened transceivers
    - Makefile: build and install all four overlays
    serenity-common library (avionics/firmware/common/):
    - CMakeLists.txt: static library target linking sbus_input.c
    - include/sbus_input.h: full public API — sbus_frame_t, sbus_ctx_t,
    sbus_open/close/channel_to_us; SBUS protocol constants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
    [bmon_ina2xx.c]
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2026-06-05 avionics/CAPE-B-2: add §13 antenna filter chains (EMI hardening)
    Each on-board RF transceiver now has a dedicated filtered antenna path:
    - FL_LORA / FL_SIK: Johanson 0915LP15B0100E BPF (902–928 MHz, 0.6 dB IL)
    - FL_WIFI: Johanson 2450BP15B050E BPF (2400–2500 MHz, 0.5 dB IL)
    - D_ANT_LORA / D_ANT_WIFI / D_ANT_SIK: Semtech RCLAMP0502BTCL ESD shunt
    (0.15 pF — chosen to avoid antenna detuning at 915 / 2400 MHz)
    - J_SMA_LORA / J_SMA_WIFI / J_SMA_SIK: SMA PCB bulkhead jacks, shells to PGND
    - J_SIK_ANT: Hirose U.FL-R-SMT-1 pad receives SiK RFD900x module pigtail
    New lib_symbols: PGND, BPF_915, BPF_2400, RCLAMP0502B, Conn_SMA, Conn_UFL
    LORA_ANT and WIFI_ANT global net labels added at module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
    [CAPE-B-2.kicad_sch]
2026-06-05 Revision Q: Hardened Avionics Baseline — EMI-hardened v2 capes at all positions; v1 and old design variants archived
    Rev Q is a comprehensive design checkpoint. Key changes:
    Avionics (v2-only standardisation):
    - All 8 nodes now use EMI-hardened v2 capes (Cape-A-2 / Cape-B-2 / XCVR-49MHZ-2)
    at every position. Placement: v2·v2·v2·v2 (was v2·v1·v1·v2). Inner bays B and D
    upgraded from v1 standard to v2 hardened capes.
    - Cape-A-1, Cape-B-1, XCVR-49MHZ-1 KiCad files archived to avionics/kicad/archive/
    - Cape-A-1, Cape-B-1, XCVR-49MHZ-1 gerbers archived to avionics/gerbers/archive/
    - Cape-A v1 and Cape-B v1 DTS overlays archived to avionics/firmware/dts/*/archive/
    - Active DTS: k3-am6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
    [CAPE-A-1-B_Cu.gbl, CAPE-A-1-B_Mask.gbs, CAPE-A-1-B_Paste.gbp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]
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2026-06-07 feat: complete battery and power distribution system (Rev Q)
    Hardware (PDB-2):
    - avionics/kicad/PDB-2.md: custom 4-layer 90×65 mm power distribution
    board spec replacing generic PDB-BEC; dual redundant 5 V/10 A SMPS
    (TPS54620 × 2, diode-OR'd); 6 V/5 A servo SMPS (TPS54540); 150 A
    MAXI main fuse + 4 × 40 A mini-blade ESC branch fuses; hardware-
    coordinated protection (40 A branch clears first on ESC short);
    BQ76930 6S cell monitor with DSG FET (AON6556) hardware disconnect;
    5 × INA226 current monitors (I2C 0x40–0x44); all connected to
    Cape-A-2 Bay A via J_EXT_I2C JST-GH.
    Firmware:
    - bmon_ina2xx.h/.c: extended INA226 driver with current-sense mode;
    adds bmon_ina226_confi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
    [bmon_ina2xx.c, cell_mon_bq769x0.c, pwr_fault.c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]
2026-06-07 feat(pdb2): per-EDF isolation, shield ground, harness spec, FC signal routing
    PDB-2.md:
    - ESC branch schematic: add three-layer stall isolation (Layer 2: C_DECn
    470 µF per-output bulk cap; Layer 3: CM_ESCn Würth 7440640500 per-output
    CM choke) with J_SHLD_ESCn chassis ground lugs for cable shield drain.
    - Connectors section: add J_PGND_BATT, J_SHLD_ESC1–5, J_SHLD_5V/6V, and
    PGND via-pads J_SHLD_I2C/ALERT/NTC so every connector has a shield ground
    point; update JST-GH part names to SM04B/SM02B-GHS-TB(LF)(SN).
    - New "ESC Control and Telemetry Signal Routing" section: FC assignment table
    (Port Fwd→FC1, Port Aft→FC2, Stbd Fwd→FC2, Stbd Aft→FC3), single-FC
    failure matrix c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
    [bmon_ina2xx.c, pwr_fault.c]
2026-06-07 Phase 11 Rev Q: EMI hardening, battery mount, Kaylee rename
    EMI hardening (500 W/m² design target):
    - Kaylee.md: two-stage CM filter (CM1+CM2 Würth 7440640500, ~80 dB cascade),
    Y-caps C_Y1/C_Y2 (4.7 nF/250 V Y2, Kemet SA305E472MAR) to chassis,
    DM bypass C_DM1 (10 µF X7R 1210), I2C TVS D_I2C (NXP PRTR5V0U2X),
    shielded 1.5 mm 6061-T6 aluminum enclosure + CHO-SEAL 1217 gasket (≥60 dB SE),
    Pflitsch 750M-series EMC cable glands (360° shield bond), J_CHASSIS pad.
    - POWER_DISTRIBUTION.md §6: 500 W/m² threat environment section, 11-stage
    EMC strategy table, updated architecture diagram.
    Battery mount (docs/BATTERY_MOUNT.md):
    - CG analysis: battery centroid at 84 mm from nose achie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
    [bmon_ina2xx.c, cell_mon_bq769x0.c, pwr_fault.c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]
2026-06-07 Add PWR-DIST-1 power distribution board and VTOL thrust analysis (Rev Q)
    - docs/POWER_SYSTEM_Q.md: complete power system analysis for Rev Q.
    Documents the critical VTOL thrust deficit: 50mm budget EDFs produce
    T/W = 0.48:1 (cannot hover). Phase 7 XRP 80mm EDFs reach T/W = 1.34:1
    (marginal). Corrects the erroneous T/W = 1.47 figure in README that
    incorrectly summed the horizontal rear EDF into vertical VTOL lift.
    Includes battery sizing, wire gauge table, ESC selection, MIL-B-5087B
    bonding strap spec, W&B analysis, and mounting location.
    - avionics/kicad/PWR-DIST-1.kicad_sch: KiCad schematic for the power
    distribution board. Components: J_BAT (AS150/XT150 battery input),
    F_MA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
    [PWR-DIST-1.kicad_sch]
2026-06-07 Rev Q: Wash/Zoë Ethernet PHYs, field connectors, Rev Q documentation propagation
    Implements TODO tasks 1.4.2–1.4.5 and 1.5.1. Renames Cape-B-2 callsign
    from "Mr. Universe" to "Zoë" throughout per CLAUDE.md (2026-06-07).
    Wash (CAPE-A-2) — task 1.4.2 + 1.4.4:
    - Dual EMI-hardened Ethernet PHY: DP83825I ×2 (RMII0→PHY1 addr 0x01,
    RMII1→PHY2 addr 0x02); HX1188NL magnetics ×2; TPS62933 1.8V ×2;
    PRTR5V0U2X TVS ×4; SRF2012-100Y CMC ×2; J_ETH1 + J_ETH2 (SM06B-GHS)
    - Field connectors: J_PWR, J_CAN (CAN_A_H/L), J_485 (RS485_A_P/N),
    J_1553 (BUS_1553_A_P/N), J_GPS, J_SERVO (CH0–CH3), J_ESC (ESC_PWM_0–2)
    - All connector MPs → PGND star; title block: rev Q, date 2026-06-07
    - CAPE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
    [CAPE-A-2.kicad_sch, CAPE-B-2.kicad_sch]
2026-06-08 Implement Rev Q naming throughout: avionics bay room names (1.5.1) and cape character names
    Bay renaming (task 1.5.1):
    - Bay A → Shepherd's room, Bay B → Inara's shuttle,
    Bay D → River's room, Bay E → Simon's medbay
    - All "Book" references → "Shepherd" in PACE tables
    - Updated across all docs, code comments, specs, and FreeCAD scripts
    Cape character names (replaces cape designators in all prose):
    - Cape-A-2 → Wash throughout (Wash is the FC/flight-control cape)
    - Cape-B-2 → Zoë throughout (Zoë is the CN/comms-logging cape)
    - Combined references (Cape-A-2/B-2) → Wash/Zoë
    - File paths (CAPE-A-2.md, gerbers/CAPE-A-2/, etc.) unchanged
    - Cape-A-1 / Cape-B-1 (archived) unchan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
    [pwr_fault.h, sbus_input.h]
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2026-06-09 docs(power): archive POWER_SYSTEM_Q + PWR-DIST-1; add §§12-14 to POWER_DISTRIBUTION
    Archive superseded documents:
    - docs/POWER_SYSTEM_Q.md → archives/docs-superseded/ (phase numbering mismatch,
    wrong EDF spec 228g vs XFly 1240g, wrong AUW, wrong connector/fuse sizing)
    - avionics/kicad/PWR-DIST-1.kicad_sch → avionics/kicad/archive/ (old design:
    ANL fuse, ACS758, AS150 connector, UBEC modules — superseded by Kaylee design)
    - avionics/kicad/PWR-DIST-1.md → avionics/kicad/archive/
    Add to POWER_DISTRIBUTION.md with authoritative numbers from TODO.md / CLAUDE.md:
    - §12 VTOL Thrust Analysis: 2×2,232 g nacelle thrust = 4,464 g total (90% stator
    efficiency per CLAUDE.md); Phase 5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
    [PWR-DIST-1.kicad_sch]
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2026-06-10 feat(avionics): generate Kaylee PDB KiCad files (pro/sch/pcb) Rev A
    - Kaylee.kicad_pro: project settings, 4 net classes (VBAT 6mm trace,
    PGND 6mm, POWER_5V 0.5mm, Default 0.3mm), DRC rules (0.15mm clearance)
    - Kaylee.kicad_sch: complete 229 kB schematic on A1 sheet, all sections:
    battery input (CM1+CM2 two-stage EMI filter), main bus disconnect FET
    (AON6556 + BQ76930 DSG gate), main INA226 shunt (0x44), 4× ESC branches
    (fuse/decap/CMC/shunt/INA226 per branch, 0x40-0x43), ESC5 DNP (Phase 11),
    dual TPS54620 5 V BEC (diode-OR'd, 5.3V→5.0V), TPS54540 6 V BEC, BQ76930
    6S cell monitor, PRTR5V0U2X I2C TVS, signal connectors (J_I2C/ALERT/NTC)
    - Kaylee.kicad_pcb: 90×65 mm 4-layer FR4-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
    [Kaylee.kicad_pcb, Kaylee.kicad_sch]
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2026-06-10 feat(avionics/kicad): Kaylee PDB DRC clean and Gerbers generated (Rev A)
    Eliminated all 0.0 mm clearance and shorting violations from the
    Kaylee power distribution board generator gen_kaylee_pcb.py:
    - R_FB1_1/2: moved y=10→14 to clear U_BEC_5V_1 thermal pad (EP) bottom
    - R_FB2_1: moved y=30→34 to clear U_BEC_5V_2 EP; R_FB2_2 moved x=84.5→86
    to exit J_5V pin circle x-range while remaining below EP in Y
    - C_BEC_SV_OUT: moved y=59→56 so both THT pad circles clear J_ALERT
    MP pads at y=58.6 by ≥0.58 mm (constraint |cap_y−58.6| ≥ 0.846 mm)
    - R_ALERT: moved x=59→66 to clear J_I2C pad1 (PGND) and pad3 (PDB_SCL)
    DRC result: 0 shorting_items, 0 clearance violations at <0.15 mm.
    A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
    [Kaylee-B_Courtyard.gbr, Kaylee-B_Cu.gbl, Kaylee-B_Fab.gbr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]
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2026-06-12 fix: correct all remaining cape PCB dimension references to 55×35 mm
    Wash (Cape-A-2) and Zoë (Cape-B-2) — and the Cape-A-1/Cape-B-1 predecessors
    they replaced — are all 55×35 mm PCBs per Edge.Cuts. Corrects the incorrect
    early estimates (85×55 and 90×60) that propagated into documentation.
    Files updated:
    - TODO.md: panel-cut sizes (85×55→62×42, 90×60→55×35), bay footprint references,
    Simon stack note, Malcolm enclosure note; standoff hole patterns flagged TBD
    pending PCB layout
    - avionics/kicad/archive/ARCHIVE-REVQ.md: Cape-A-1, Cape-A-2, Cape-B-1,
    Cape-B-2 dimension entries
    - avionics/kicad/archive/CAPE-A-1-no-comment.kicad_{pcb,sch}: title-block
    comment dimensions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
    [CAPE-A-1-no-comment.kicad_pcb, CAPE-A-1-no-comment.kicad_sch]
2026-06-12 avionics: wire second Ethernet (ETH2) on Wash; preserve Wash/Zoë layout work
    Wash cape now carries a fully-wired second Ethernet channel. The newly
    placed ETH2 / ETH2-PHY (ADIN1300) / T-ETH2 (749010012A) footprints were
    unconnected; this assigns their nets to mirror the ETH1 topology exactly:
    ETH2 (JST-GH-4P) --ETH2_LINE_{TX,RX}{P,N}--> T-ETH2 --ETH2_{TX,RX}{P,N}-->
    ETH2-PHY, reusing the host-side nets already broken out on the PB2-P2
    header (RMII1_* bus, shared MDIO/MDC, PHY2_INTRN/PHY2_RSTN, VCC2_ETH/
    GND/GND2_ETH). 44 pads assigned across the three parts (ETH2-PHY 32,
    T-ETH2 8, ETH2 4); diff-pair chains verified end to end.
    Also preserves the manual component rearrangements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
    [Wash.kicad_pcb, Zoë.kicad_pcb]
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2026-06-12 avionics(Wash): add I2C GPIO expander and ESC-PWM connector
    Resolves the two open I/O gaps from the connector-wiring pass:
    * U-GPIO (PCA9555DB, SSOP-24, I2C addr 0x20) + C-GPIO 100nF decoupling.
    P0_0..P0_5 -> GPIO_EXP_A..F now source the six GPIO-A..F expansion
    connectors over the existing I2C1 bus (no SoC pins consumed). A0/A1/A2
    to GND; INT and the spare P0_6/P0_7 + P1_x left NC.
    * ESC-PWM (JST-GH SM05B, 5-pin): pins 1-4 -> DSHOT0..3, pin 5 -> GND,
    giving the four EDF ESC/BDSHOT PWM outputs a connector to the nacelle
    harness.
    GPIO_EXP_A..F, DSHOT0..3, and I2C1_SCL/SDA are now 2-pad (fully netted).
    New parts placed at tentative locations for the user to finalise; I2C1
    pull-ups t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
    [Wash.kicad_pcb]
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2026-06-16 Document consistency audit: attribution, units, and revision-status fixes
    - Reconcile hull-source attribution across active docs/PCBs: misubisu
    (thingiverse.com/thing:7330462) is the current 24in Rev P-R1 source;
    Peter Farell (printables.com/model/548545) is documented as the
    historical Rev M/18in source. Fixed conflated/wrong citations in
    LICENSE_AND_ATTRIBUTION.md, serenity-rev-r.jsx, REVN_BUILD_GUIDE_24IN.md,
    PROTO_PRINT_DAVINCI_JR.md, TODO.md, bom_revP/Q/R.json, Wash/Zoe/
    XCVR-49MHZ-2 PCB silkscreens, and graphical-build-guide SVGs.
    - Restore "Griffing Technology LLC" company markings on PCB title blocks
    and silkscreens (reverted an earlier incorrect removal) per author
    c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
    [Wash.kicad_pcb, XCVR-49MHZ-2.kicad_pcb, Zoë.kicad_pcb]
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2026-06-20 Fix 49 MHz Emma link regulatory citation: Part 95 RCRS -> Part 15 §15.235
    Part 95 Subpart C (Radio Control Radio Service) covers only 26-28 MHz,
    72 MHz, and 75 MHz -- it has no provisions for 49 MHz. The 49.82-49.90 MHz
    band Emma actually uses is governed by 47 CFR Part 15 §15.235, an
    unlicensed intentional-radiator rule with a field-strength limit, not a
    licensed/license-exempt personal radio service.
    Also corrects a previously-unnoticed downstream consequence: §15.235's
    10,000 µV/m-at-3m field-strength limit converts to an EIRP ceiling of
    only ~30 µW (-15.2 dBm), about 35 dB below the 100 mW the project's
    antenna/power budget assumed. malcolm_antenna_spec.md, Emma.md, and
    REFERENCES.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
    [Emma.kicad_pcb, Emma.kicad_sch]
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2026-06-20 Resolve Emma 49 MHz §15.203 connector violation with RP-SMA
    J2 changed from a standard SMA edge jack (Amphenol 132289) to its
    reverse-polarity counterpart (Amphenol 132289RP) -- identical PCB
    footprint, reversed mating-pin gender -- so generic standard-SMA
    antennas/cables cannot mechanically connect, satisfying 47 CFR
    §15.203's "unique coupling" provision for intentional radiators.
    Updates Emma.kicad_sch (lib symbol + J2 instance Value/Description),
    Emma.kicad_pcb (footprint Value/Description properties, ANT silkscreen
    label, ESD note), Emma.md, and the Malcolm GCS wiring/antenna-spec docs
    that mirror Emma's connector on the ground station side. REFERENCES.md
    and TODO.md updated from "ope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
    [Emma.kicad_pcb, Emma.kicad_sch]
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2026-06-20 Fix Emma ERC/DRC errors: schematic parser crash, J1 pin mirroring, 12 PCB shorts
    Schematic (Emma.kicad_sch):
    - Remove stray ;; comment that silently broke KiCad's S-expr parser,
    causing ERC to fail to load the file entirely (CLAUDE.md prohibits ;/#
    comments in KiCad files for exactly this reason).
    - Fix Conn_JST_GH_06P pin Y-offset sign: J1's SHIELD/MP pin and all six
    numbered pins were mirrored relative to where their wires/power symbols
    were actually drawn, leaving the PGND bond and J1 unconnected.
    - Add PWR_FLAG markers on the J1 GND/+5V/PGND nets to silence the
    power-pin-not-driven check (standard KiCad mechanism for sub-circuit
    schematics with no local power source).
    - Fix F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
    [Emma.kicad_pcb, Emma.kicad_sch]
2026-06-20 Emma PCB: fill GND/+5V zones, stitch 65 GND pads to plane
    - Refill the In1.Cu GND and In2.Cu +5V zones via pcbnew's ZONE_FILLER;
    the zones were declared but had never actually been filled and
    saved, so SMD pads near them had zero real copper connection despite
    being nominally on a covered net. This alone resolved 24 missing
    connections with no design change.
    - Add 65 stitching vias (0.6mm, matching the project's secondary via
    spec) connecting previously-unstitched GND pads to the In1.Cu plane,
    verified via kicad-cli pcb drc and pcbnew's own pad bounding-box
    geometry after an early geometry script proved unreliable for
    rotated footprints.
    - Add 3 short connecting traces where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
    [Emma.kicad_pcb]
2026-06-20 Emma: fix LoRa (RFM95W) SPI/reset/GND pin mapping against verified datasheet
    The LoRa footprint had SPI1_MISO/MOSI/CLK/SPI1_CS_LORA wired to pads 10-13,
    which per the official HopeRF RFM95W/96W/98W datasheet (Table 2, v2.0) are
    GND/DIO3/DIO4/3.3V, and LORA_RESETN wired to pad 2, which is actually MISO.
    This is a wrong-pin-number error, not a missing connection: fabricated as-is,
    the SPI clock signal would have driven directly onto the module's 3.3V supply
    pin. Corrected pads 2-6 to MISO/MOSI/SCK/NSS/RESET and pads 1/8/10 to GND,
    matching the verified pinout now cited as REF-RFMOD-001 in REFERENCES.md.
    Also corrects a false-positive finding from earlier in the session: CAPE-B IF
    (JST GH 6P)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
    [Emma.kicad_pcb]
2026-06-21 Emma PCB: route +3V3 net (31 pads, no plane existed) via obstacle-aware A*
    +3V3 had zero copper anywhere on the board -- not even the LDO's own
    output pins were connected to anything. Unlike GND/+5V, this board has
    no spare internal layer for a +3V3 plane (only F.Cu/In1.Cu-GND/In2.Cu-
    +5V/B.Cu exist), so this net is distributed as point-to-point F.Cu
    traces rather than a pour.
    Built as a minimum-spanning-tree over all 31 pad locations (rather than
    star-routing each back to the LDO individually) and routed each MST
    edge with a grid-based A* pathfinder against a clearance-inflated
    obstacle map of every other-net pad, track, and via -- the same
    approach used by hand for the DDS_RF reroute earl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
    [Emma.kicad_pcb]
2026-06-21 Emma PCB: route 14 more nets (+5V, +5V_FILT, PA_INT, RF_LPF_N1, etc.) via A*
    Continuation of the +3V3 routing approach: MST + obstacle-aware A* per
    net, against a fresh obstacle map (pads + existing tracks + vias) taken
    from the actual current board state. An earlier attempt in this same
    session used a stale obstacle snapshot captured before the +3V3 work
    landed, so the router never saw the 224 +3V3 segments as obstacles and
    produced 45 new shorts; that attempt was reverted before committing
    anything. This version re-extracts obstacles fresh and inflates
    clearance to account for both traces' half-widths, not just one.
    14 of 27 candidate nets fully or partially routed this pass: +5V,
    +5V_FIL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
    [Emma.kicad_pcb]
2026-06-21 Emma: reconcile docs with PCB, fix silk text height rule, add FCC ID placeholder
    - Emma.md: add an as-built full component table generated directly from
    Emma.kicad_pcb's footprint list (DDS/PA/LPF/T-R-switch/LNA chain, AFSK
    modem, UART/SBUS digital chain, power supply, Ethernet PHY + isolation
    transformer, LoRa module, connectors) -- the existing BOM tables only
    covered the XCVR-49MHZ-1 delta, leaving most of the board undocumented.
    Notes the GND2_ETH/VCC2_ETH isolation requirement inline.
    - Emma.kicad_pro: standardize min_text_height to 0.6mm. All 78 silk
    labels use 0.65mm text against the previously-declared 0.8mm minimum
    (pre-existing since before this session); 0.6mm matche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
    [Emma.kicad_pcb]
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2026-07-04 Fix CI: black/mypy/editorconfig/textlint on Emma reconciliation
    Resolves the four super-linter + flake8 failures on the emma-zoe-schematic-
    migration branch:
    - PYTHON_BLACK: black-format gen_emma_sch.py and mod_emma_pcb.py.
    - flake8: drop duplicate Counter import (F811) and unused sys/uuid imports;
    split semicolon statements (E702); strip trailing whitespace (W291).
    - PYTHON_MYPY: annotate module-level NETCOUNT: dict (var-annotated).
    - EDITORCONFIG: stop tracking the Emma.kicad_pcb.premod-bak /
    Emma.kicad_sch.stub-bak backups (tabs tripped editorconfig-checker; the
    pre-change originals remain in history at 52e62e6). Add *.premod-bak /
    *.stub-bak to avionics/kicad/.gitignore.
    - NATUR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
    [gen_emma_sch.py, mod_emma_pcb.py]
2026-07-04 Clear Emma pre-existing DRC debt + schematic-parity so CI validator passes
    Editing Emma.kicad_pcb pulled it into the CI KiCad validator's --changed-since
    scope, which surfaced 35 pre-existing hard DRC violations plus 26 new
    schematic-parity conflicts. All fixed at root cause (validator now reports
    0 hard for Emma.kicad_sch ERC and Emma.kicad_pcb DRC):
    - Schematic parity (26 net_conflict): gen_emma_sch.py now emits GLOBAL labels
    (bare net names match the PCB; local labels were named "/GND"). mod_emma_pcb.py
    assigns net-less pads the canonical "unconnected-(REF-PadN)" nets that the
    schematic no-connects generate.
    - Solder-mask bridges (20): board solder-mask expansion was 0.10 mm (~2x n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
    [Emma.kicad_pcb, Emma.kicad_sch]
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2026-07-05 Emma: route RSSI sub-circuit after user placement (0 hard DRC)
    The user manually placed the 4 RSSI parts (RSSI_CMP + RSSI_RH/RL/CBY) on B.Cu in
    the RF section and marked "NET validation, DRC & Routing" as the next step.
    - Validated: sch<->pcb parity exact (refs + net sets match); the placement
    introduced 0 hard DRC violations (0 shorting/clearance/courtyard/solder-mask).
    - Routed the sub-circuit via avionics/kicad/route_emma_rssi.py (pcbnew), DRC-tuned:
    GND -> B.Cu tie of the 3 GND pads + one via to the F.Cu GND pour at RL.2
    RSSI_REF -> B.Cu weave through the 0.5 mm mid-channel around the wide CMP.4 pad
    +3V3 -> internal (RH.1/CBY.1/CMP.2) + board tie to LNA By
    RSS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
    [Emma.kicad_pcb]
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2026-07-11 Vera: fix unloadable PCB (restore In2.Cu, rebuild outline) + dot-grid/3D analysis
    PCB was committed in a broken state after the 1"-wide (25.4 x 69.85 mm) resize:
    - LAYER TABLE was missing In2.Cu(6), leaving an invalid 3-copper-layer stackup ->
    "Failed to load board" (broken across several commits). Restored In2.Cu to the
    4-layer stackup (F.Cu/In1.Cu/In2.Cu/B.Cu), matching Emma. Board loads again.
    - Edge.Cuts was malformed/self-intersecting from the resize (invalid_outline x4).
    Rebuilt a clean rounded rectangle 69.85 x 25.4 mm, 3.81 mm corners -> 0 invalid.
    - Verified: sch<->pcb net parity is EXACT (88 = 88 nets) -- the nets were never
    scrambled; the board just would not load. Remaini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
    [Vera.kicad_pcb]
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

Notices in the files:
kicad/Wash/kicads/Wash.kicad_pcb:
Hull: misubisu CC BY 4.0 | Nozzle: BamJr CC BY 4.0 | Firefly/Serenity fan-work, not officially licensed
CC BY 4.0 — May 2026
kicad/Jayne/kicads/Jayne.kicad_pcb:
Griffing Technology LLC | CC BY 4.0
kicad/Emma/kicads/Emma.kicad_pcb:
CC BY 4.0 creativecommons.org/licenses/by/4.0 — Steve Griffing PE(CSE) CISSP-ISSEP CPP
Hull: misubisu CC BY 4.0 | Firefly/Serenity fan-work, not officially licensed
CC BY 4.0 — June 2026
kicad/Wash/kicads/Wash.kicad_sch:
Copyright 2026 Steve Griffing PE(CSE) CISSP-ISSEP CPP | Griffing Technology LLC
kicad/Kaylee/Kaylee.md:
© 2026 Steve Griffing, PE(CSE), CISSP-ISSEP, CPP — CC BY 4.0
